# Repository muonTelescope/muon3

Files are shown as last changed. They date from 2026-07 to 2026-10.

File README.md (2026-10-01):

# Muon3: a networked cosmic-ray muon station

**In plain English:** muons from cosmic-ray showers pass through us all the time. A plastic scintillator tile gives off a
tiny flash when one crosses it. A silicon photomultiplier (SiPM) turns that flash into a current pulse, and a small board
counts pulses that arrive in several stacked tiles at once. Muon3 is the next-generation station for the Georgia State
University [gLOWCOST](https://cosmic.gsu.edu/) network: cheap, identical detectors in classrooms and labs that log how the
muon rate follows air pressure, temperature and space weather.

A station is **four decommissioned sPHENIX inner-HCal tiles** (Hamamatsu S12572-33-015P SiPMs), stacked 100 mm apart in a
printed ABS frame. Each tile carries one wavelength-shifting fiber in a closed loop, under a reflective coating and a
light-tight wrap. **One 337 × 40 mm, 4-layer, USB-powered board**, assembled by JLC on one side, stands behind the tiles with
its long axis along the stack: its four channel cells sit right behind the four SiPM boards, so the four micro-coax cables are
short (57 mm) and identical. The hub (USB-C, ESP32, bias supply, pressure/temperature) sits between tiles 1 and 2. A printed
three-segment case covers the board. There is no display: the station reports over USB and Wi-Fi.

| | |
|---|---|
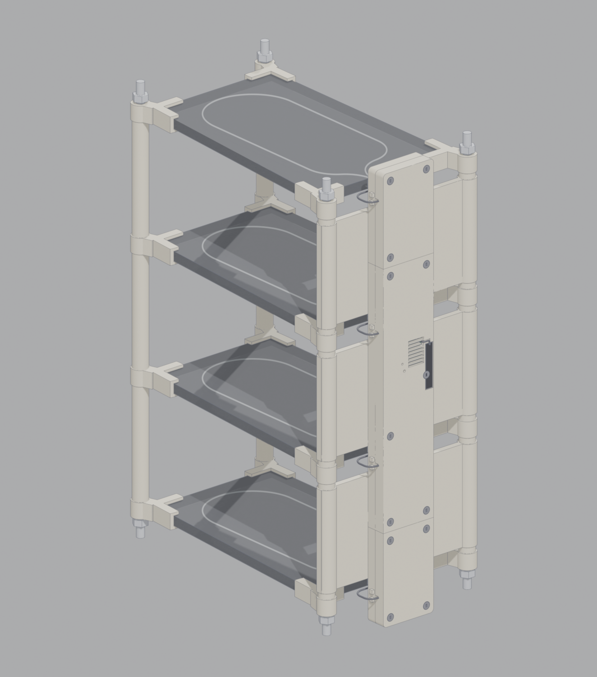
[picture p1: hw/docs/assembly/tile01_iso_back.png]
The station, from behind
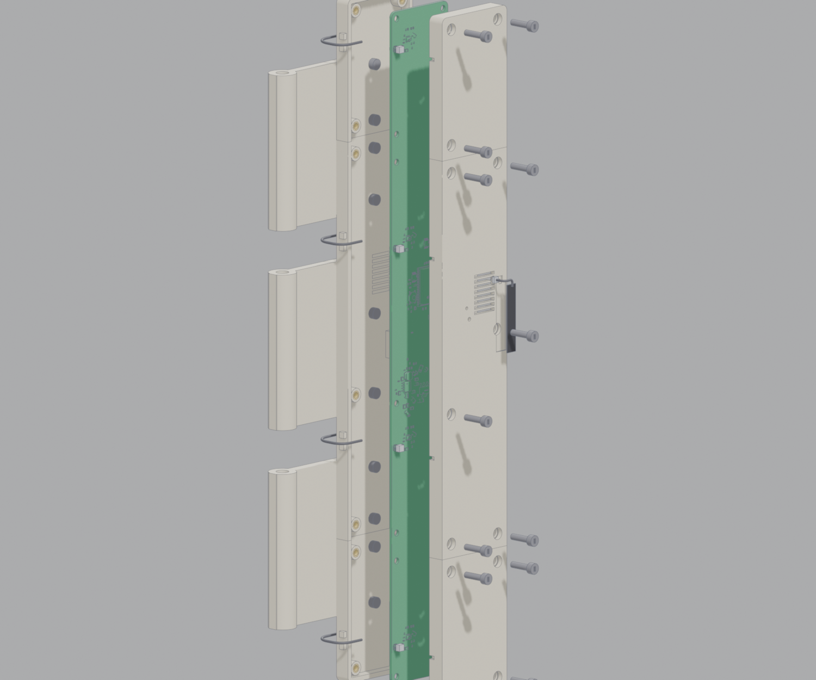
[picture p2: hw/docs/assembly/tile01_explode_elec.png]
Electronics, exploded
|  |  |

## Contents

0. [Quick start](#quick-start) · [How a muon becomes a count](#how-a-muon-becomes-a-count) · 1. [What you get](#1-what-you-get) · 2. [Bill of materials and cost](#2-bill-of-materials-and-cost) · 3. [Install it: step by step](#3-install-it-step-by-step)
· 4. [Test and calibrate](#4-test-and-calibrate) · 5. [The 12 tile shapes](#5-the-12-tile-shapes) · 6. [The electronics](#6-the-electronics)
· 7. [Simulated performance](#7-simulated-performance) · 8. [Regenerate the design files](#8-regenerate-the-design-files)
· 9. [Design notes, open questions, repository map](#9-design-notes-open-questions-repository-map)

---

## Quick start

```bash
git clone git@github.com:muonTelescope/muon3.git && cd muon3/hw
bun run parts && bun run build && bun run drc      # the board: Gerbers, BOM, CPL in hw/out/ (section 8 lists the tools to install first)
freecadcmd case/case.py                            # the three case segments
TILE=6 freecadcmd case/assembly.py                 # the frame, plate and tile stack for tile shape 6 (any of 1–12)
python tools/station_test.py board                 # factory test over USB, once a board is assembled
```

## How a muon becomes a count

1. **Light.** A cosmic-ray muon crossing a 7 mm polystyrene tile deposits about 1.5 MeV and makes some 13 000 scintillation photons
   (blue, 420 nm). About 2 500 of them are absorbed by the 1 mm wavelength-shifting fiber in the tile and re-emitted at 476 nm (green);
   light trapped in the fiber travels both ways round the closed loop to the SiPM. Of the order of 150 photons reach the SiPM and about
   35 are detected (PDE 25 %): the **photoelectrons (p.e.)**.
2. **Current.** The S12572 SiPM, biased at 53–83 V, turns each p.e. into a fast current pulse (gain about 2.3 × 10⁵). The bias comes from
   the MC34063 boost converter on the board and reaches the SiPM over the same micro-coax that carries the signal back.
3. **Voltage.** A transimpedance amplifier (OPA356, 33 kΩ) gives 5.8 mV per p.e., so a mean muon makes a 209 mV pulse about 370 ns long.
4. **Decision.** A comparator (LMV7219) fires when the pulse passes a threshold set by a DAC: 29 mV, 5 p.e., rejects dark counts (single
   p.e.) and keeps essentially every muon that crosses the tile.
5. **Count.** The ESP32-S3 time-stamps each edge (MCPWM capture, 12.5 ns) and counts singles (PCNT); coincidences of the four tiles are
   formed in firmware, together with pressure and temperature (BME280), and sent over Wi-Fi or USB. The muon rate follows air pressure,
   temperature and space weather: that is what the gLOWCOST network logs. `sim/python/coincidence_rates.py` computes the coincidence and
   accidental rates; `sim/python/sipm_to_tot.py` maps SiPM charge to time over threshold.

---

## 1. What you get

- **Identical channels.** Channel 0 is placed and routed once; cells 1–3 are exact copies at a 100 mm pitch (copper identical
  to 2 µm, checked on every build with `hw/tools/cell_identity.py`). The pitch is the tile pitch, so cell *k* is behind tile *k*.
- **The SiPM bias never leaves the case.** Each tile's micro-coax plugs into a U.FL jack inside the case.
- **External antenna.** An ESP32-S3-WROOM-1U-N16R8 sends its Wi-Fi/BLE through a U.FL pigtail to a flat antenna on the lid.
- **Fits every tile.** All 12 inner-HCal tile shapes, from the 121 mm wide, nearly rectangular tile 01 to the 403 mm
  parallelogram tile 12, get a frame and a fiber loop generated from their outline.
- **Self-testing.** The board tests itself over USB in 2 minutes (nothing plugged in), and calibrates each tile's gain from its
  own dark counts.

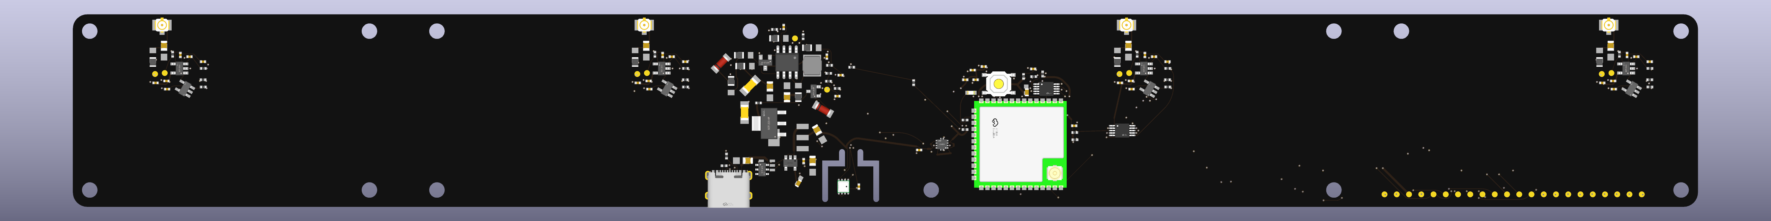
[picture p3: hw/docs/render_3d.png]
The board, 337 × 40 mm: four channel cells along the top edge, the hub with USB-C, BME280 island and ESP32 in the middle, the probe row at the right


```text
 tile ─ micro-coax ─► U.FL in the case (shell = bias via 47 kΩ) ─► OPA356 TIA (33 kΩ ‖ 2.7 pF) ─► LMV7219 ─► HIT_n ─► ESP32-S3
   ×4 (identical cells)           ▲                               ▲ VREF (DAC B·A)             ▲ VTH_n (DAC A)      PCNT + MCPWM
             MC34063 boost → 10 k / 1 µF RC ─ HV (53–83 V) ◄─ HV_TRIM (DAC B·B) ◄──────────────────────────── HV_EN
                         └──────────── HV_MON (÷ 27.7) ────────────────────────────────────────────────────► ADC
 INJ (GPIO) ─ 10 k/1.1 k ─ 1 pF into each input: 0.33 pC = 9 p.e. self-test
 BME280 (slotted thermal island, ≥ 20 mm from any input) · SC7A20H tilt · USB-C 5 V → AMS1117 3V3 + TLV75733 3V3A
```

---

## 2. Bill of materials and cost

### Board (JLC assembles it; 155 parts, 45 lines)

Upload `hw/out/muon3-gerbers.zip`, `hw/out/bom.csv` and `hw/out/cpl.csv` to JLCPCB: **4 layers, 1.6 mm, top-side assembly only**,
337 × 40 mm. Parts come from LCSC; the full list is [`hw/parts/INDEX.md`](hw/parts/INDEX.md).

| Line | Part | Per board | Share |
|---|---|---|---|
| BME280 (pressure, temperature) | C92489 | $4.46 | 27 % |
| ESP32-S3-WROOM-1U-N16R8 (Wi-Fi, BLE, U.FL antenna connector) | C3013946 | $4.10 | 24 % |
| MCP4728 DAC × 2 | C478093 | $3.06 | 18 % |
| OPA356 TIA × 4 | C183100 | $1.83 | 11 % |
| LMV7219 comparator × 4 | C20613263 | $0.99 | 6 % |
| U.FL jack × 4, SC7A20H, AMS1117, MC34063, TLV75733 | | $0.95 | 6 % |
| the other 34 lines, mostly 0402/0805 passives | | $1.19 | 7 % |

**Cost at 100 boards (importer: GSU): parts $16.58 + PCB $6.19 + JLC assembly $1.32 = $24.08 ex-works, $35.57 landed in the US**
($105.57 per board for the two Berlin prototypes). The PCB price is an estimate ($0.045 per cm² of 4-layer board, 135 cm² here): get a
quote. Cheaper variants (saves about $6.3 per board, landed $35.6 → $26.4): BME280 → SPA06-003 (same package, pressure + temperature,
$0.51), drop the second MCP4728 (fixed VREF divider, PWM HV trim), ESP32 N4 module, drop the tilt sensor, two extended parts →
basic parts. Not worth it: a 2-layer board (saves $1.50, loses the ground plane), dropping the analog LDO, cheaper op-amps.

### Mechanics and cables (you print and buy these)

| Part | Qty | How |
|---|---|---|
| Corner clip (ABS, 12.4 mm thick, 8.0 mm slot, M6 hole) | 16 | printed, flat |
| Spacer tube (Ø 12 / Ø 6.4) | 18 (6 × 87.6 mm, 12 × 4.8 mm) | printed; the long ones can be aluminium tube |
| Back plate bar (one piece for tiles 1–11; two halves + a splice plate for tile 12) | 3 | printed, lying on its back |
| Case base + lid, segments A (71 mm), B (200 mm), C (71 mm) | 3 + 3 | each flat |
| M6 threaded rod, about 345 mm | 4 | cut from 1 m stock |
| M6 nut + washer | 8 + 8 | |
| M3 × 5.7 heat-set insert | 13 (lid) + 10 (plate bars) (+ 12 for the tile-12 splices) | pressed in with a soldering iron |
| M3 × 12 socket-head screw (ISO 4762) | 13 | lid, through the board's edge holes |
| M3 × 6 socket-head screw (ISO 4762) | 10 (+ 12 for the tile-12 splices) | case floor to plate bars |
| U.FL to U.FL micro-coax, Ø 1.13 mm, 70 mm | 4 | tile SiPM board to station board; four equal lengths |
| 2.4 GHz FPC antenna, 35 × 7 mm, with U.FL pigtail | 1 | sticks in the lid recess |
| Tile wrap: 100 µm Al foil, 30 µm cling film, 100 µm black vinyl, epoxy (EPO-TEK 301 class) | 4 tiles | plus the tile's 50 µm painted reflector |
| 4 decommissioned sPHENIX inner-HCal tiles with their fibers, SiPMs and SiPM boards (from GSU) | 4 | of one shape |

Print in ABS at 0.2 mm layers, 4 perimeters, 30 % infill, 100 °C bed, enclosure closed. The longest parts are case segment B
(206 mm) and the plate bars (up to 212 mm): both fit a 220 mm bed.

---

## 3. Install it: step by step

All M3 joints are **socket-head screws into heat-set inserts** (no nuts, no glue). Press the inserts in first: hold each on its hole
with a soldering iron at 220–240 °C and push it flush. Everything below is generated for your tile shape (1–12): run the commands in
[section 8](#8-regenerate-the-design-files) with `TILE=<n>` to get the exact STL/STEP files.

### Step 0: order and print

1. Order the board (section 2). Order or print the parts (`hw/out/case/case_{base,lid}_{A,B,C}.stl`, and the clips, spacers and bars
   from `hw/out/assembly/tileNN/`).
2. Check the board when it arrives: `python hw/tools/station_test.py board` (section 4).

### Step 1: the tiles

The tile is a slab of extruded polystyrene with **one Kuraray Y11 fiber laid in a closed loop**: both ends leave the flat SiPM edge
side by side, each runs through an S-bend of 25 mm radius onto a leg, the two legs run down the tile and a semicircle closes the
loop near the far edge. Over the tile go the **50 µm painted reflector** and the **wrap: 100 µm aluminium foil, 30 µm cling film,
100 µm black vinyl**, each following the tile's outline and open only where the coupler sits (Aidala et al., IEEE TNS 65 (2018),
Table II and Fig. 6). Tiles 01, 06 and 12, bare, with the fiber in its groove and the coupler and SiPM board on the SiPM edge:

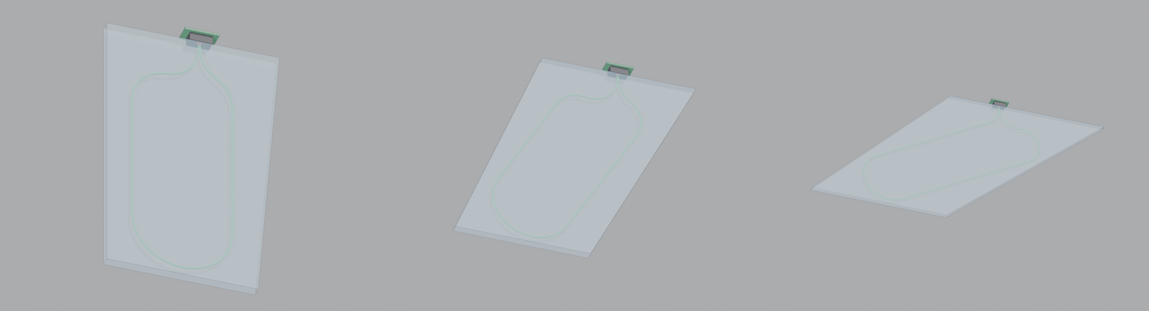
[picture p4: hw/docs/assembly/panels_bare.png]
Panels 01, 06 and 12


The same tile with its layers lifted off one by one (reflector, foil, cling film, vinyl):

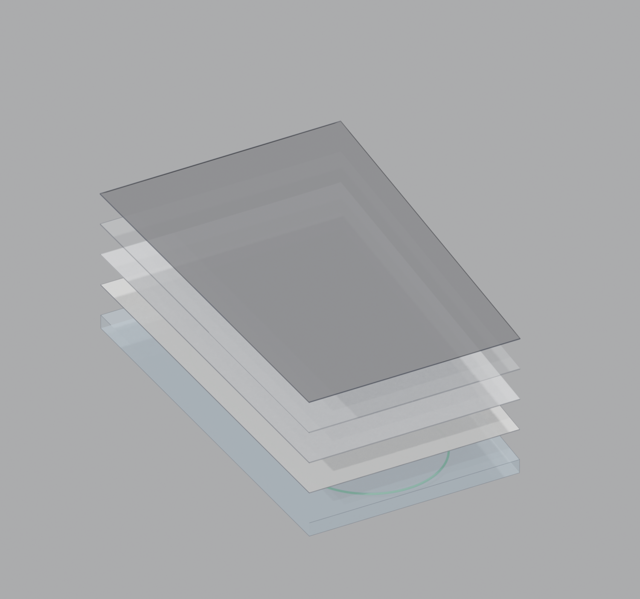
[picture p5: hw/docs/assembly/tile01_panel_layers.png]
Coating and wrap layers


1. Lay the fiber in its groove (epoxy) and cut and polish both ends flush with the SiPM edge.
2. Put on the reflector and the wrap (foil, cling film, vinyl), open at the coupler.
3. Glue the coupler block (16 × 6 × 8 mm, black ABS) on the SiPM edge over the two fiber ends, with the SiPM board and its U.FL
   jack behind it. Both ends, 1.2 mm apart, face the one 3 × 3 mm SiPM across a 0.75 mm air gap.

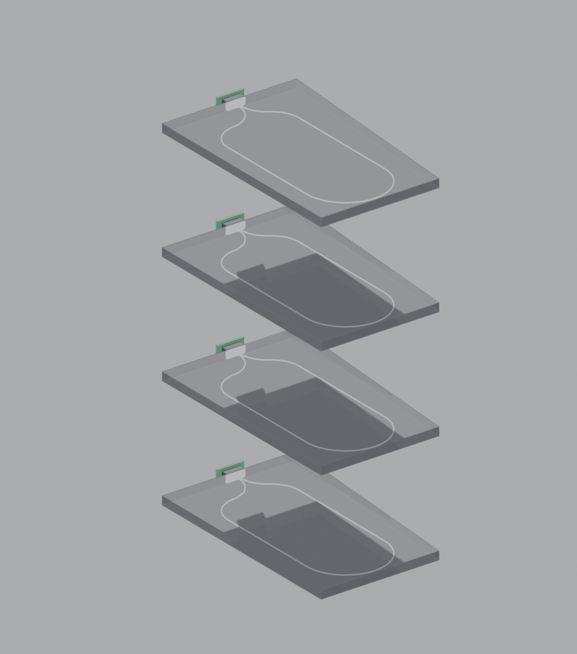
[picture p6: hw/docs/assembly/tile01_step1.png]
Step 1


### Step 2: the frame

Slide the four rods through the bottom clips, add the nuts, then build up: spacer, tile in its four corner clips, spacer, next tile.
The four clips of a tile clamp its corners in an 8.0 mm slot; the tile is never drilled. The rods sit 8.5 mm outside each corner, so
they never touch the scintillator.

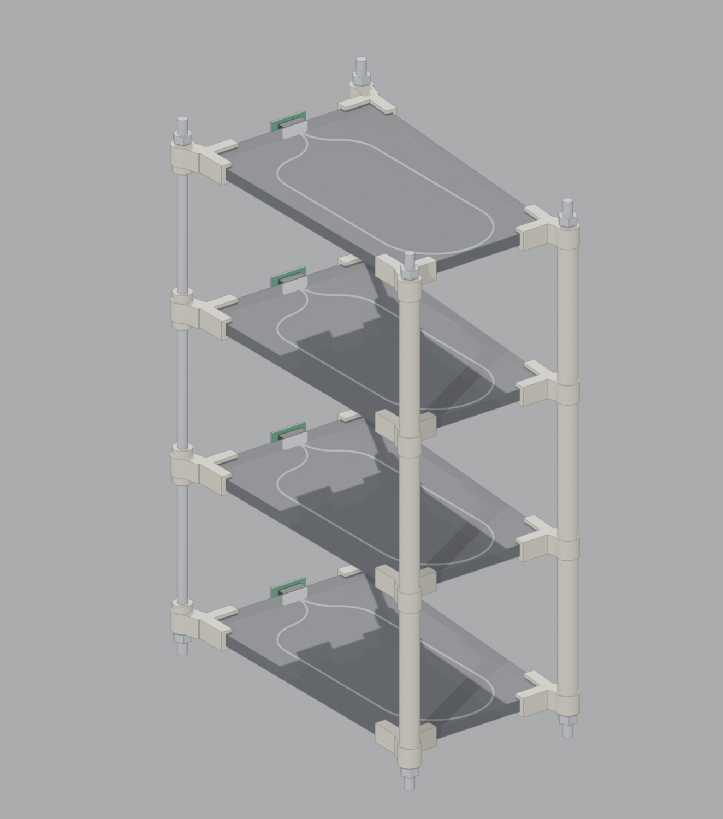
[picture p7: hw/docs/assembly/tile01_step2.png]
Step 2


### Step 3: the back plate

A bar replaces the back-rod spacer between tiles 0/1, 1/2 and 2/3. Each bar's two sleeves slide onto the back rods (bars are at
z = 50, 150 and 250 mm, clear of the SiPM boards at z = 0, 100, 200, 300, so the coax passes between them). For tile 12 each bar is
two halves joined by a splice plate on the front face (4 × M3 × 6).

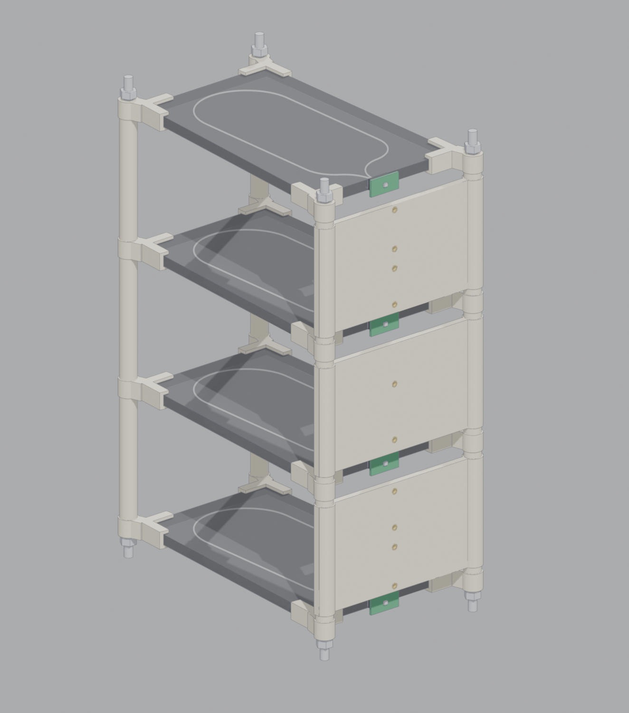
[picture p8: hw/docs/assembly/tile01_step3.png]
Step 3


### Step 4: the electronics

Press the inserts into the three case bases. Drop the board onto the bosses of the bases (the board's underside has no parts; the
heads of the floor screws sit in the 4.6 mm gap under it), close the three lids (13 × M3 × 12) and screw each segment's base to the
bars (10 × M3 × 6). The segments join at the bars (board x = 68.5 and 268.5 mm). The USB-C opening is on the far long wall, the
BME280 vent beside it.

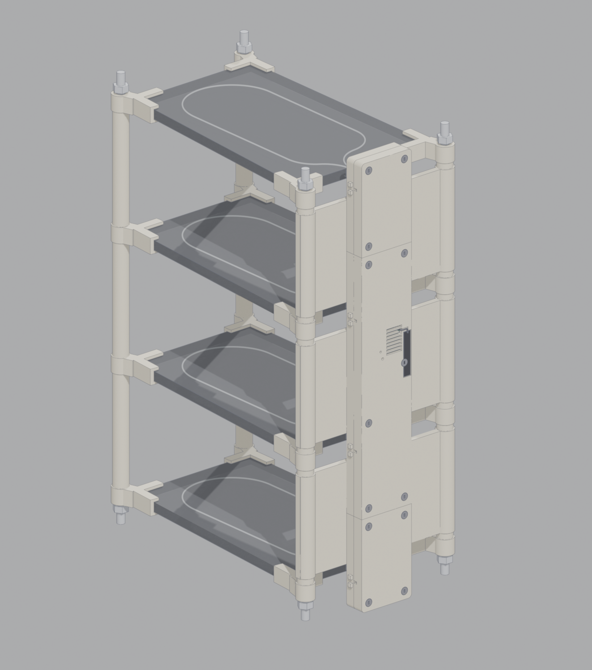
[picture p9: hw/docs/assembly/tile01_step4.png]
Step 4


### Step 5: cables and antenna

Plug a 70 mm micro-coax onto each tile's SiPM board, route it out to the case wall, and click its other plug onto the board's jack
through the notch in the lid skirt, then lay it in the zip-tie bridge on the wall. All four cables are identical. Stick the FPC antenna
in the lid recess and click its pigtail onto the ESP32 module's U.FL through the lid hole.

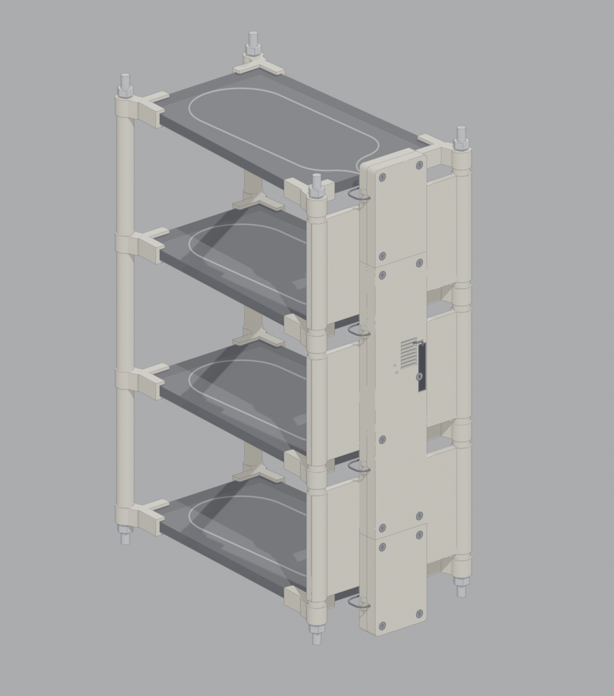
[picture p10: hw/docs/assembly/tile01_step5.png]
Step 5


### Sections (tile 01)

Through the SiPM edge (scintillator with its coating and wrap, fiber in its groove, coupler, SiPM, board, plug) and through the case
at the hub (lid, board on its 4.6 mm standoffs, base, plate bar):

| | |
|---|---|
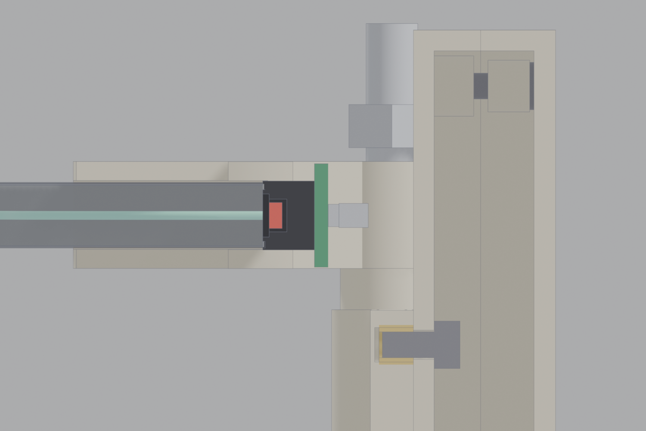
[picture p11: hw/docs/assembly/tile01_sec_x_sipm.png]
SiPM section
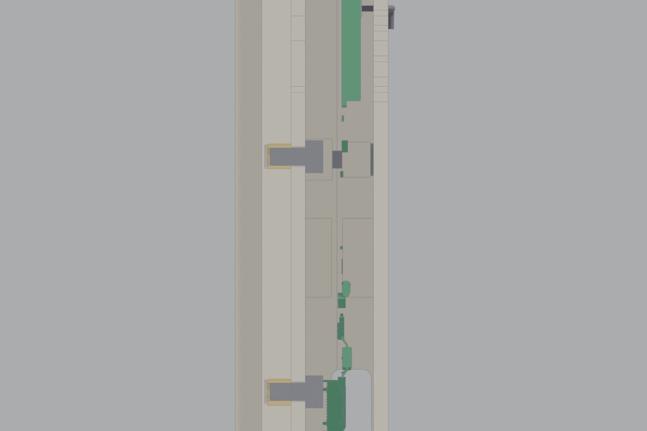
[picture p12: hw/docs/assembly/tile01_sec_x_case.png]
Case section
|  |  |

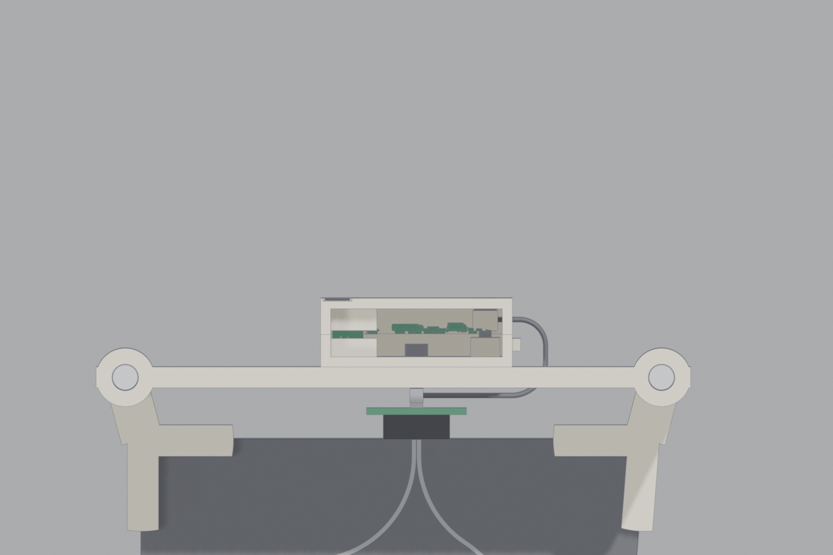
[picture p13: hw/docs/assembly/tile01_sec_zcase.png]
Case, plate bar and cable, cut at the hub


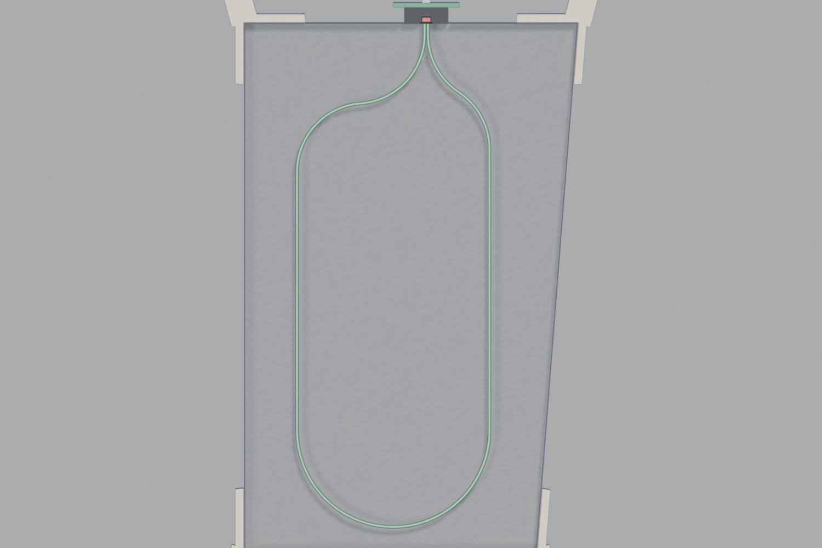
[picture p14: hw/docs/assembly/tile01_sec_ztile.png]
Fiber in the top tile, cut at its mid-plane


The widest shape (tile 12), from the back:

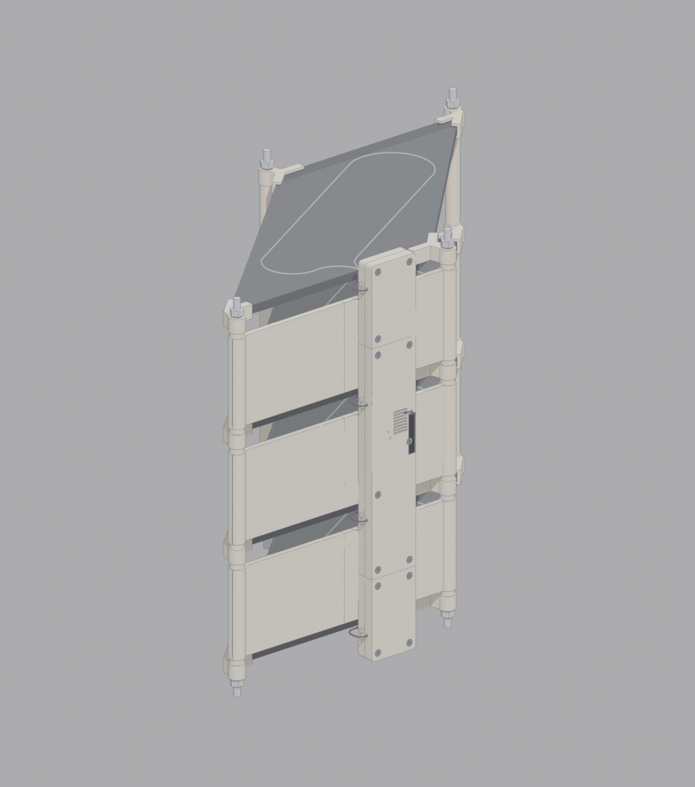
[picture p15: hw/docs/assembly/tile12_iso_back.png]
Tile 12 from the back


### Case and plate details

- **Three printed segments** (71, 200, 71 mm, each with a base and a lid, split at the board mid-plane) because the board is 337 mm long;
  the joints sit on the plate bars. The lid screws sit 7 mm either side of a joint so that no boss is cut.
- **Coax entry.** A 1.8 × 2.4 mm notch in the lid skirt above each U.FL takes the micro-coax; a small zip-tie bridge on the wall takes the
  strain off the plug. The bias on the U.FL shells stays inside the closed case.
- **BME280 chamber.** Ribs above and below the island (stopping 0.15 mm short of the board), vented to room air through eight 1.6 mm
  slots in the far wall. **Hot side:** eight 1.6 × 14 mm chimney slots in the floor and lid over the ESP32 and AMS1117.
- **External antenna.** A Ø 3.2 mm hole in the lid over the module's U.FL jack passes the pigtail to a 35 × 7 × 0.7 mm recess on the
  lid's outer face, along the far edge.
- **Mounting.** Ten Ø 3.4 mm holes in the base floors take M3 × 6 screws into the bars' inserts (two per segment per bar).

### Step 6: install

Put the stack where it will stay (tiles horizontal). Plug a USB-C power source into the hub's USB-C port (a bank that can deliver
the station's 40–120 mA continuously: many switch off below 50–100 mA). Give it Wi-Fi credentials over the USB serial port.
*(The firmware is not written yet: its USB line protocol is specified in `hw/tools/station_test.py`.)*

---

## 4. Test and calibrate

Every board is tested and calibrated by the ESP32 itself, driven from a laptop over USB:

```bash
python hw/tools/station_test.py board          # factory test: nothing plugged in, about 2 min
python hw/tools/station_test.py tile --ch 0    # per tile, at installation: about 10 min per channel
```

No scope or fixture is needed. The probe row (22 pads, 2.54 mm pitch, far long edge at the right-hand end of the board) and the
TIA/GND scope pair in each channel cell are for diagnosing a board that fails. The station has one status LED (next to the BOOT
button, through a light pipe in the lid): the firmware is specified to blink fast during the 10 s self-test, slowly while counting and
to stay on in a fault.

**How it works.** Each channel has a 1 pF injection capacitor driven from the INJ GPIO through a 10 k / 1.1 k divider: each edge puts
0.33 pC on the TIA input, which is 9 photoelectrons (p.e.). The firmware sweeps the threshold DAC and counts HIT pulses: the threshold
at which half the injected pulses still fire measures the whole chain at once. The bias checks itself through HV_MON (HV ÷ 27.7). The
tile calibrates its own gain: in the dark a SiPM fires single p.e., the count rate against threshold falls in a staircase, and the step
spacing is 1 p.e. (set the bias so it is 5.8 mV, then put the threshold at 5 p.e. = 29 mV). The same staircase, repeated every few
minutes, is the running gain servo.

### Factory test (`board`)

| Step | What the firmware does | Pass | Source |
|---|---|---|---|
| 1 | Scan both I2C buses | BME280 0x76, SC7A20H 0x19, MCP4728 0x60 on I2C0 and I2C1 | design |
| 2 | Read BME280 pressure | 850–1090 hPa | — |
| 3 | HV_EN low, read HV_MON | 2.5–5.5 V (USB 5 V minus the boost diode; not 0 V) | [SIM] ≈ 4 V |
| 4 | HV_EN high, TRIM = 0 / 1.0 / 2.048 V | 80–86.5 V / 65.5–71.5 V / 50–56 V | [SIM] 83.0 / 68.3 / 52.9 V |
| 5 | Store HV(TRIM) line; leave the bias at TRIM 2.048 V and HV_EN low | — | — |
| 6 | Per channel: VTH staircase with no injection | noise edge ≤ 8 mV below VREF | [SIM] < 3 mV |
| 7 | Per channel: VTH staircase with INJ pulses, 50 % point | 85–135 mV below VREF | [SIM] 109 mV |
| 8 | Join the test access point, read RSSI (the external antenna must be on the lid) | ≥ −65 dBm at 2 m | first prototype |

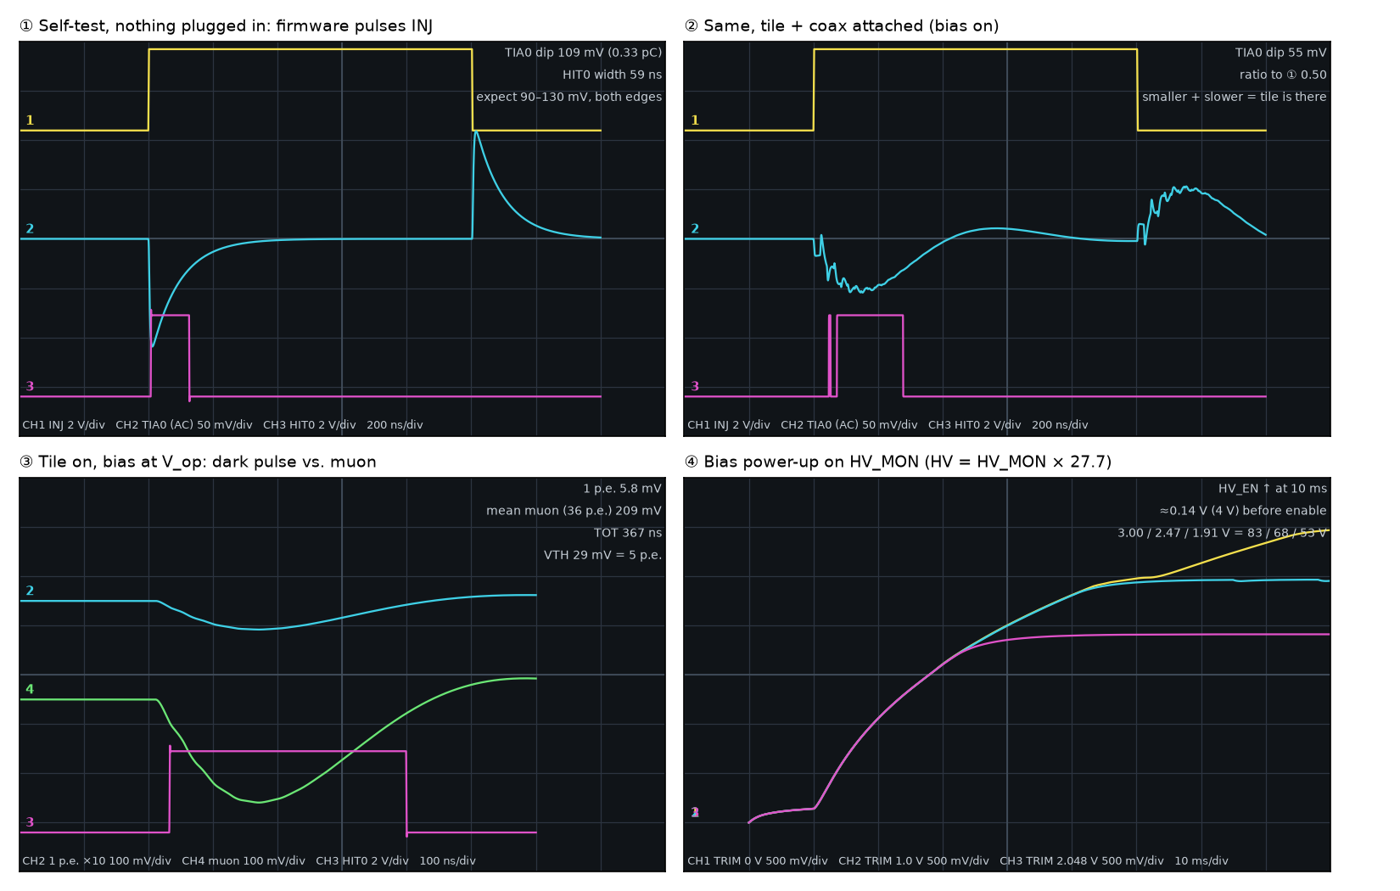
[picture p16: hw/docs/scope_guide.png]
Simulated scope screens


*Simulated scope screens (what you should see on the probe points): ① injection with nothing plugged in: a 109 mV dip follows each INJ
edge and HIT0 fires on the negative one. ② With a tile and coax attached the charge shares the SiPM's 320 pF and the dip halves (55 mV).
③ A single dark pulse (5.8 mV, shown ×10) and a mean muon (36 p.e., 209 mV, time over threshold ≈ 370 ns). ④ The bias power-up on
HV_MON: ≈ 4 V until HV_EN goes high at 10 ms, then 60–90 ms to settle.*

### Per-tile calibration (`tile`)

1. Attach the tile and close the light-tight wrap. Set the bias to the tile's operating voltage V_op (from the Hamamatsu/GSU sheet);
   the firmware closes the loop on HV_MON using the stored HV(TRIM) line.
2. **Staircase.** Sweep VTH 1–40 mV below VREF, 200 ms per step. The peaks in −d(log rate)/dVTH sit between p.e. steps; their
   spacing is the 1 p.e. amplitude.
3. If the step is not 5.8 mV, move V_op by ΔV = (5.8 / step − 1) · (V_op − V_bd) and repeat.
4. Threshold = 5 p.e.; store `pe_n`, `vth_n` and V_op in NVS.
5. With the tiles stacked, run the coincidence plateau: V_op ± 1 V in 0.25 V steps, 5 min each. The rate should be flat within its
   statistical error. Expect a few counts per minute for a 12 × 19 cm tile (cosmic muons: about 1 per cm² per minute × the geometric
   acceptance). Measure each tile's efficiency with the coincidence method (three tiles fire, does the fourth?).

### Diagnosing a failed board

| Probe (row, left → right) | Expect |
|---|---|
| GND · 5V · 3V3 · 3V3A | 0 · 4.8–5.2 · 3.25–3.35 · 3.25–3.35 V |
| VREF · VTH0–3 | as set (default 2.50 V; VTH = VREF − 29 mV) |
| HIT0–3 | 0 V idle, 3.3 V pulses |
| INJ | 0/3.3 V square during self-test |
| HV_EN · HV_TRIM · HV_MON | 0/3.3 V · 0–2.048 V · HV ÷ 27.7 |
| DAC_C · DAC_D | spare DAC outputs |
| SDA0 · SCL0 | I2C0, 3.3 V idle |

- Scope the TIA with a ground spring on the TIA/GND pair in each cell. **Never clip a scope ground to a U.FL shell: it carries the bias.**
  The four cells are identical, so a good channel next door is your reference.
- A TIA pinned at VREF with no injection dip: dead op-amp or open input. Pinned at a rail: shorted Cf/Rf or an input tied to the shell.
- HV stuck at ≈ 4 V with HV_EN high: the BSS123 gate (HV_GATE), the 150 µH inductor or the MC34063 current sense (2.2 Ω).
- No Wi-Fi with a good board: the antenna pigtail is not clicked onto the module's U.FL, or the FPC antenna is not on the lid.

---

## 5. The 12 tile shapes

The shapes differ a lot: tile 01 is almost a rectangle (121 × 191 mm); tile 12 is a 403 × 191 mm parallelogram leaning 45°. All are
drawn at the same scale (rods, corner clips, the fiber loop, the coupler on the SiPM edge at the top):

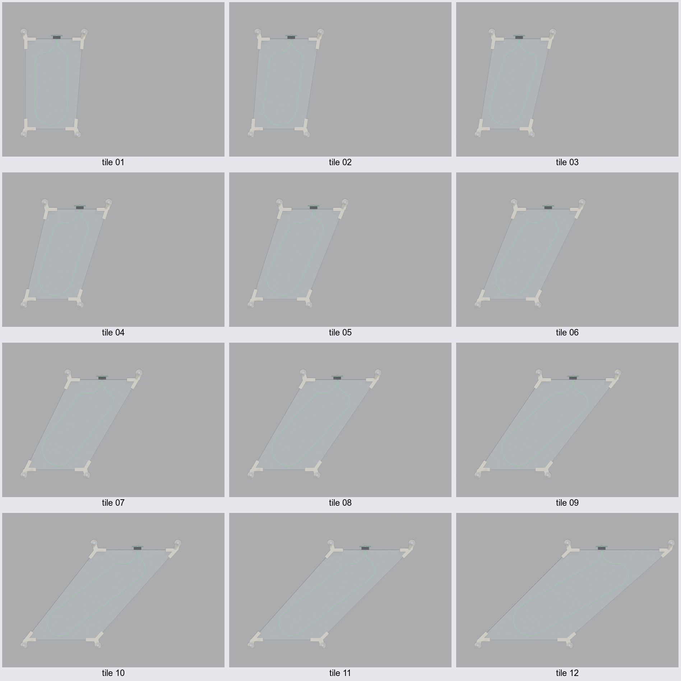
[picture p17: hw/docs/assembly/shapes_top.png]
All 12 tile shapes, same scale


<!-- SHAPES -->
| Tile | Bounding box (mm) | Left-edge slant | Stack footprint x × y × z (mm) | Fiber loop: lean, legs apart, length | Distance tile → fiber: mean / 95 % / max | Plate bars | Coax (mm) | ABS volume |
|---|---|---|---|---|---|---|---|---|
| 01 | 121 × 191 | 0° | 143 × 244 × 344 | 0.0°, 70 mm, 439 mm | 15 / 30 / 44 mm | 3 × 1 piece | 57 | 413 cm³ |
| 02 | 140 × 191 | 4° | 162 × 244 × 344 | 7.5°, 70 mm, 441 mm | 15 / 32 / 45 mm | 3 × 1 piece | 57 | 418 cm³ |
| 03 | 151 × 191 | 9° | 173 × 244 × 344 | 17.5°, 70 mm, 446 mm | 14 / 32 / 47 mm | 3 × 1 piece | 57 | 413 cm³ |
| 04 | 172 × 191 | 13° | 194 × 244 × 344 | 17.5°, 70 mm, 457 mm | 14 / 31 / 46 mm | 3 × 1 piece | 57 | 420 cm³ |
| 05 | 192 × 191 | 18° | 214 × 244 × 344 | 25.0°, 70 mm, 467 mm | 15 / 32 / 48 mm | 3 × 1 piece | 57 | 425 cm³ |
| 06 | 214 × 191 | 22° | 236 × 244 × 344 | 30.0°, 70 mm, 479 mm | 15 / 32 / 54 mm | 3 × 1 piece | 57 | 431 cm³ |
| 07 | 237 × 191 | 26° | 259 × 244 × 344 | 37.5°, 70 mm, 501 mm | 15 / 33 / 54 mm | 3 × 1 piece | 57 | 438 cm³ |
| 08 | 262 × 191 | 30° | 284 × 244 × 344 | 42.5°, 70 mm, 519 mm | 16 / 34 / 63 mm | 3 × 1 piece | 57 | 447 cm³ |
| 09 | 289 × 191 | 34° | 311 × 244 × 344 | 47.5°, 70 mm, 542 mm | 16 / 34 / 65 mm | 3 × 1 piece | 57 | 457 cm³ |
| 10 | 319 × 191 | 38° | 341 × 244 × 344 | 52.5°, 55 mm, 580 mm | 16 / 37 / 66 mm | 3 × 1 piece | 57 | 469 cm³ |
| 11 | 334 × 191 | 42° | 356 × 244 × 344 | 52.5°, 55 mm, 571 mm | 16 / 37 / 73 mm | 3 × 1 piece | 57 | 463 cm³ |
| 12 | 403 × 191 | 45° | 425 × 244 × 344 | 60.0°, 70 mm, 643 mm | 19 / 45 / 91 mm | 3 × 2 halves + splice | 57 | 535 cm³ |
<!-- /SHAPES -->

- **One fiber, one closed loop per tile.** The sPHENIX goal is a deposit within about 25 mm of a fiber. A single loop meets that only
  near its legs: the table gives the mean, 95 % and maximum distance from a point of the tile to the fiber (about 15 mm on average,
  30–45 mm at the 95 % mark, up to 90 mm in the corners of the long tile 12). `cad/sphenix_hcal/scripts/fiber_loop.py` chooses the lean,
  position and leg spacing (55–70 mm) that bring the fiber closest to each shape's area; the same loop feeds the Geant4 model and the CAD.
  The real tiles may use longer patterns on the wide shapes: **check against GSU's own drawings before cutting grooves.**
- **The coax is the same for all shapes** (the SiPM board is at the same x on every tile, the board's jacks at the same z as the SiPM boards).
- The source tile CAD (upstream sPHENIX GDML) has **no fiber, coupler, coating or wrap**; all four are added here from the published
  construction. It does have a 71 × 8.7 mm connector pocket in the SiPM edge, which the model fills (flat edge).

---

## 6. The electronics

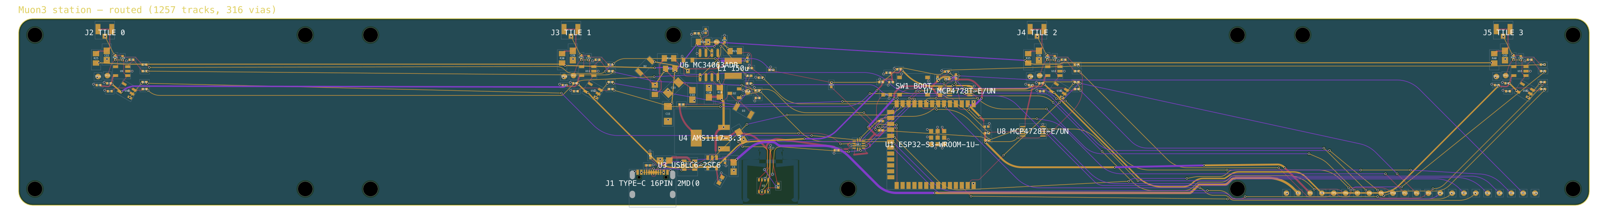
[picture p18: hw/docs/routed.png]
Routed copper


*The routed copper: tapered pad exits and parts at 15° steps where that shortens the nets.*

| | |
|---|---|
| Outline | 337 × 40 mm, 3 mm corner radius, 13 × M3 holes along the long edges (at both ends of each case segment and between) |
| Coordinates | Board x runs along the stack (x = tile z + 18.5 mm), board y across it; y = 0 is the edge the coax leaves by, y = 40 the USB-C / vent edge |
| Channel cells | 4 × (20 × 22 mm) along the coax edge, **100 mm pitch**. Each cell: a U.FL at x = 18.5 + 100k, y = 3, the 47 k / 100 nF bias feed, the TIA, the comparator and a TIA/GND scope pair. Placement, local copper, GND fan-out and silk are identical |
| Hub | x 130–207 mm, between cells 1 and 2: USB-C (x 136, far edge), bias and DAC feeds, charge injection, MC34063, AMS1117, the ESP32 (x 196, its U.FL faces +x), the BME280 island (x 156–167, far edge) |
| Stack-up | JLC 4-layer 1.6 mm: L1 signal + parts, **L2 solid GND**, L3 signal/power, L4 signal |
| Rules | 0.127/0.127 mm signal track/clearance; 0.5 mm for 5 V, 0.4 mm for 3V3, 0.3 mm for 3V3A and HV_SW; HV nets ≥ 0.26 mm to anything; 0.3/0.5 mm vias |
| BME280 island | 8.4 mm deep on the far long edge, ≥ 20 mm from any TIA input, cut free by two C-shaped slots; no plane and no plane vias on island and arm |
| Probe row | 22 pads at 2.54 mm at the right-hand end: GND 5V 3V3 3V3A VREF VTH0–3 HIT0–3 INJ HV_EN HV_TRIM HV_MON DAC_C DAC_D SDA0 SCL0 GND |
| Long nets | HV, 3V3A, VREF, INJ, VTH_n and HIT_n run 50–250 mm between the hub and the cells over the L2 ground plane; the TIA inputs stay inside their cells |

| Block | Parts | Notes |
|---|---|---|
| Input × 4 | Hirose U.FL-R-SMT-1(80) inside the case; shell = SiPM cathode = HVJ_n fed from HV via 47 kΩ with 100 nF to GND; centre = anode = SIG_n | The shell is the bias *and* the signal's AC shield. U.FL is rated 60 V AC rms / 200 V AC withstand; the bias tops out at 83 V DC |
| TIA × 4 | OPA356, Rf 33 k ‖ Cf 2.7 p, IN+ = VREF via 100 Ω / 100 nF | 5.8 mV per p.e.; 209 mV for the 36 p.e. mean muon |
| Discriminator × 4 | LMV7219, IN+ = VTH_n via 1 k / 100 nF, 33 Ω into the ESP32 | Threshold at 5 p.e. set by calibration |
| Self-test | INJ GPIO → 10 k / 1.1 k → 1 pF into every SIG_n | Each edge injects 0.33 pC = 9 p.e. |
| DACs | MCP4728 A (I2C0) = VTH0–3; MCP4728 B (I2C1) = VREF, HV_TRIM, DAC_C/D (spares) | Internal 2.048 V reference |
| Bias | MC34063 (2.2 Ω sense → 136 mA peak), BSS123, 150 µH, LL4148, 1 µF + 100 nF, 10 k / 1 µF RC post-filter; feedback 1.02 M / 20 k; TRIM → 1 k / 100 nF → 68 k into FB; HV_EN: a 2N7002 releases a clamp that otherwise holds FB high | **83.0 V at TRIM 0 V, 52.9 V at 2.048 V**; ≈ 4 V while HV_EN is low; HV_MON = HV ÷ 27.7 |
| MCU | ESP32-S3-WROOM-1U-N16R8: U.FL antenna connector, 16 MB flash, 8 MB octal PSRAM (IO35–37 reserved). USB on IO19/20 | PCNT singles, MCPWM capture (time stamp + time over threshold), coincidences in firmware |
| Power | USB-C 5 V (5.1 k Rd), USBLC6 ESD → AMS1117-3.3 (digital) + TLV75733 (analog) | No battery |
| Sensors | BME280 (0x76) on the island; SC7A20H tilt (0x19) | |

---

## 7. Simulated performance

All numbers come from simulations (`hw/sim/`, `sim/geant4/`); nothing has been measured on hardware yet.

| | Value | From |
|---|---|---|
| **Light: photoelectrons per muon that crosses a tile**, tile 01 | **36.6** (σ 13, min 15); every one of 272 crossing muons passes a 5 p.e. threshold. Tiles 03 / 06 / 09 / 12: 38.7 / 38.9 / 34.3 / 35.8 | Geant4, 150–300 muons per shape |
| Pulses: 1 p.e. / mean muon | **5.8 mV / 209 mV**, time over threshold ≈ 370 ns; threshold 5 p.e. = 29 mV | ngspice |
| Bias range | **52.9–83.0 V**; ≈ 4 V while HV_EN is low; settles in 60–90 ms | ngspice |
| Switching ripple at the TIA output | **0.04 mV pk-pk (0.007 p.e.)** (capacitor ESL, resistor shunt C, 1.5 nH shared ground) | ngspice, 5 ns steps |
| Injection self-test | 109 mV with no tile, 55 mV with a tile | ngspice |
| BME280 above room air | **+4.8 K** (low-power firmware), +8.8 K (Wi-Fi always on); mid-board would read +9.7 K | 2D thermal model |
| Wi-Fi at the TIA inputs (+20 dBm accepted, external antenna, cables included) | **0.9 / 1.6 / 9.3 / 1.1 mV peak** (cell 2 is 15 mm from the antenna feed), rectifying to ≪ 0.01 p.e. | openEMS |
| Cost at 100 boards | **$24.08 ex-works, $35.57 landed** ($16.58 parts, $6.19 PCB) | `bun run cost` |

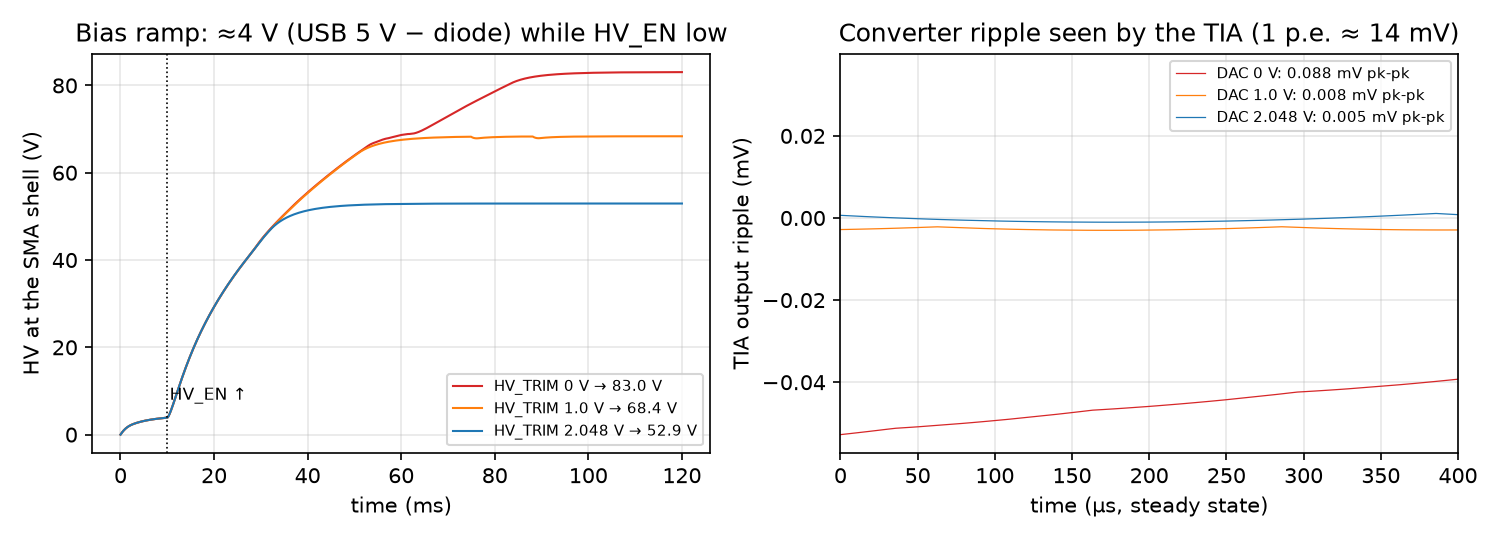
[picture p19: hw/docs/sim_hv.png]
Bias supply


### Light yield (Geant4)

The tile is modelled with one closed fiber loop, the 50 µm reflector (border surface, R = 0.95, Lambertian), the three wrap layers
(absorbing skin), the coupler and a Hamamatsu S12572-33-015P (flat PDE 0.25) across a 0.75 mm air gap. Material data: extruded
polystyrene + 1.5 % PTP + 0.01 % POPOP (n = 1.59, attenuation 2.2 m, 8000 photons/MeV, an estimate); Kuraray Y11(200) single-clad 1 mm
(PS core n = 1.59, PMMA cladding n = 1.49, EPO-TEK 301 groove n = 1.52, absorption 430 nm, emission 476 nm, attenuation 3.5 m).

| Tile | Generated / crossing | Fiber loop (length, mean distance tile → fiber) | p.e. per crossing muon: mean (σ), min | ≥ 5 p.e. |
|---|---|---|---|---|
| 01 | 300 / 272 | 439 mm, 14.5 mm | **36.6** (13.3), 15 | 100 % |
| 03 | 150 / 125 | 446 mm, 14.4 mm | **38.7** (14.9), 19 | 100 % |
| 06 | 150 / 107 | 479 mm, 14.9 mm | **38.9** (17.2), 15 | 100 % |
| 09 | 150 / 95 | 542 mm, 16.1 mm | **34.3** (10.8), 15 | 100 % |
| 12 | 150 / 97 | 643 mm, 18.8 mm | **35.8** (17.7), 6 | 100 % |

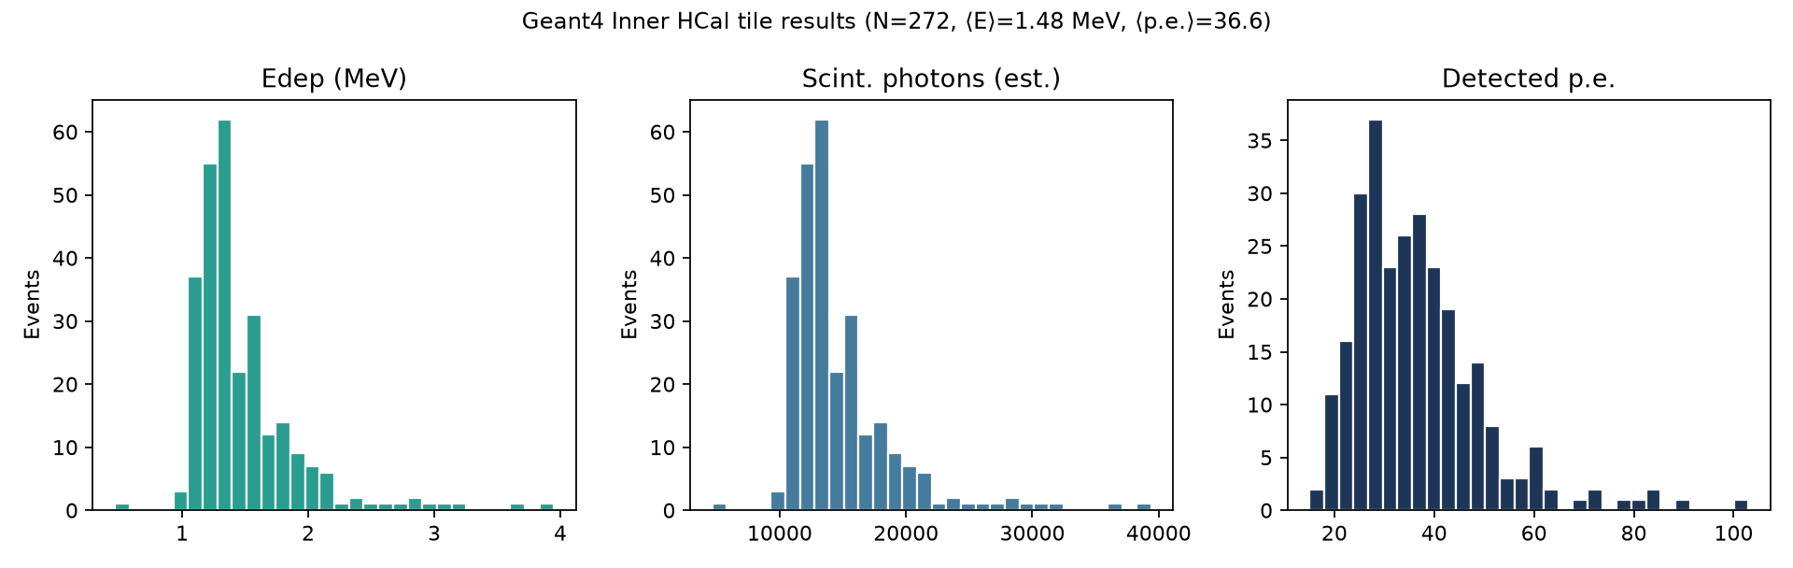
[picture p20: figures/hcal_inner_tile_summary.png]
Geant4 results


- The closed loop lets light that travels the far way round reach the SiPM: 36.6 p.e. against 21.5 for the earlier open loop (1.7 ×).
- "Crossing" means the muon deposited > 0.3 MeV; the gun is 50 mm above the tile and up to 50° off the vertical, so about 9 % of
  the muons miss the tile (more on the slanted shapes). That is a geometric acceptance loss, not a light-yield one.
- Per generated muon on tile 01: 13 100 scintillation photons → 2 540 absorbed by the fiber → 2 320 re-emitted → 156 reach the SiPM →
  33 detected.
- A first version of the loop (small, same size on every shape) gave only 24.7 p.e. on the 403 mm tile 12; the loop generator now fits
  the loop to the shape.
- **Not modelled:** the tile-to-tile variation of the groove, the polishing of the fiber ends, wrinkles of the wrap, SiPM cross-talk,
  after-pulsing and saturation (40 000 pixels, small at 36 p.e.). The yield depends on the fiber attenuation and on the light entering
  the fiber (the "WLS efficiency", 0.90): treat 36 p.e. as a simulation, not a prediction.
- Two earlier statements are withdrawn: "58 p.e. per muon" never came from the optical transport (an event-action fallback
  substituted a formula when no photon arrived; it is opt-in now, `HCAL_EFFECTIVE_YIELD=1`), and "90 % efficiency at 5 p.e." was the
  share of generated muons that hit the tile.

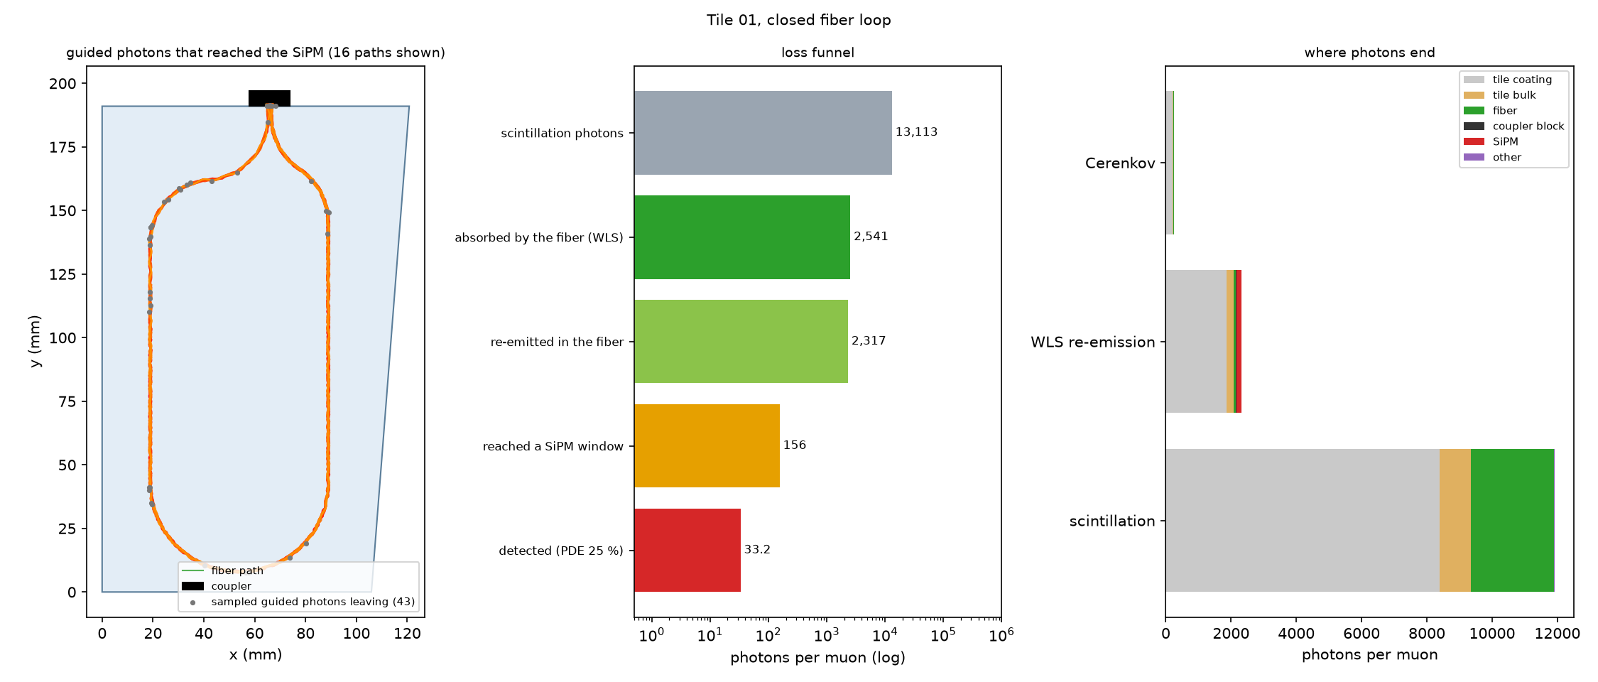
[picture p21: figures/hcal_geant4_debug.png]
Geant4 debugging: guided photons that reach the SiPM (left), the loss funnel (middle), where every photon ends (right)


How the transport was debugged (with the model as first written, 0.0–0.1 p.e. per muon; `HCAL_DEBUG=1` logs where every photon ends):
mirrored fiber pieces (`G4PVPlacement` takes the inverse rotation); Y11 absorption and emission overlapping on a coarse spectrum grid;
no refractive index on the SiPM (Geant4 kills the photon at the boundary); the reflector also sitting between tile and fiber; sharp
fiber corners and 3 mm chords (now 1° mitre-cut `G4CutTubs` chords: `G4Torus` joints made photons hop); the connector pocket (filled);
an impossible coupler (fiber ends 43 mm apart, from my old heuristic); and coating and wrap built as boxes round the bounding box (now
shells that follow the outline).

### Electronics

**Thermal.** The BME280 hangs on a slotted island on the far edge (no plane copper, four necked traces) in its own vented chamber and
reads +4.8 K above room air with low-power firmware (+8.8 K with Wi-Fi on). In the long layout the island is only 20 mm from the ESP32,
so it helps less than before. The design treats it as case temperature and takes SiPM gain from the dark-count staircase; for true tile
temperature, add a BME280 or TMP117 on a cable taped to the tiles.

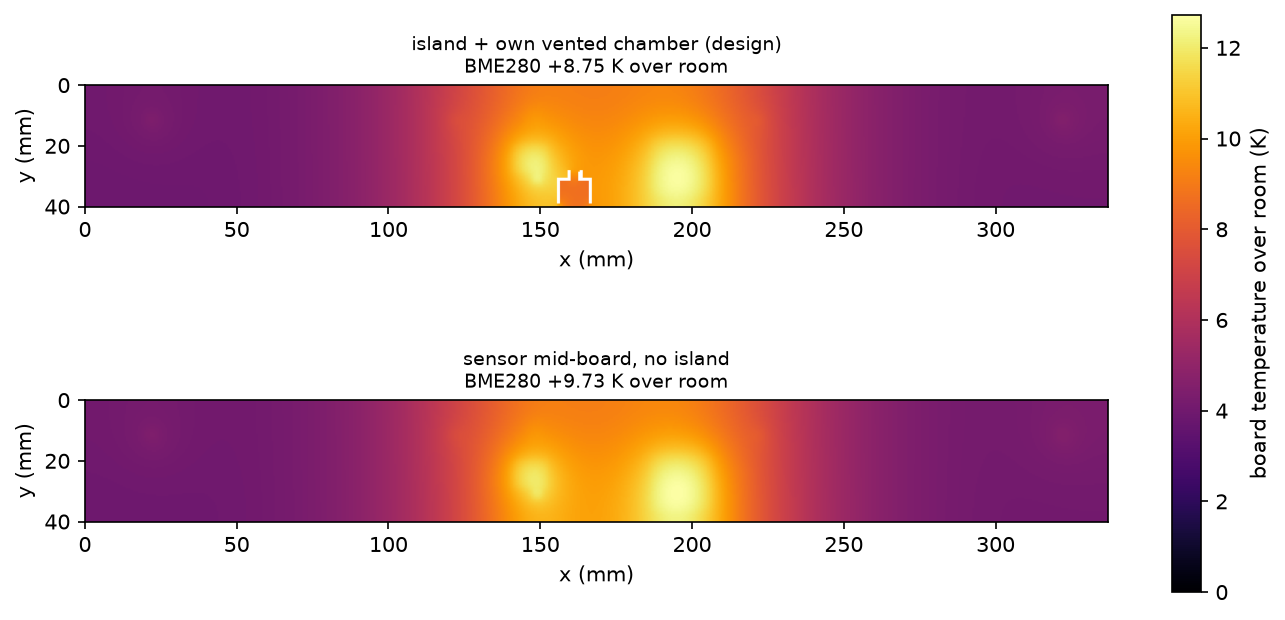
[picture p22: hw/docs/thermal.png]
Thermal model


**EMI.** The openEMS model (2.7 M cells) has the board, the case, the ESP32 can, the external inverted-L antenna on the lid, each
tile's coax shield leaving through the case wall, and the four input paths. With +20 dBm accepted the four TIA inputs pick up 0.9, 1.6,
9.3 and 1.1 mV peak at 2.44 GHz; a few mV at a CMOS op-amp input rectifies to microvolts. (In the earlier study metal cans or an ABS
cavity over the amplifiers did not help; not re-run for this layout.)

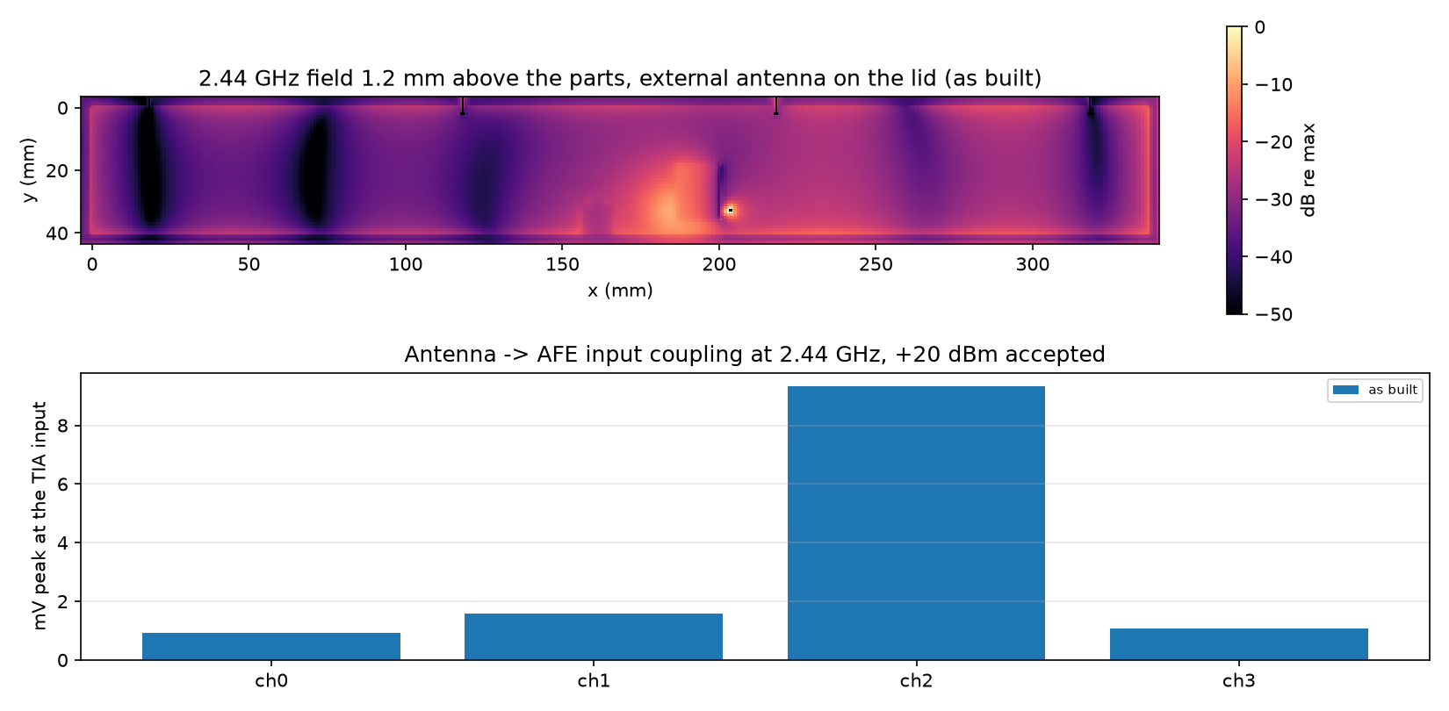
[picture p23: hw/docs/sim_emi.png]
EMI


---

## 8. Regenerate the design files

### Software you need

| Tool | Used for | Install (macOS) |
|---|---|---|
| [Bun](https://bun.sh) | board-as-code (TypeScript → Gerbers) | `brew install oven-sh/bun/bun` |
| KiCad 10 (`kicad-cli`, tested with 10.0.6) | DRC oracle, PCB STEP and 3D render | `brew install --cask kicad` |
| FreeCAD 1.x (`freecadcmd`) | case, frame and assembly | `brew install --cask freecad` |
| Blender 4.x | assembly renders | `brew install --cask blender` |
| Python 3 with numpy, matplotlib | fiber-loop generator, plots | `pip install numpy matplotlib` |
| ImageMagick (`magick`) | montages | `brew install imagemagick` |
| ngspice | bias, front end, scope screens | `brew install ngspice` |
| openEMS + Python bindings (optional) | EMI study | build from source against Homebrew (VTK 9.7); see the `CSXCAD_INSTALL_PATH=/opt/homebrew pip install --no-build-isolation CSXCAD/python openEMS/python` recipe |
| Geant4 11.4 (optional) | light yield | `micromamba create -p g4 -c conda-forge geant4 cmake make cxx-compiler` (about 3.5 GB) |

Heavy jobs (board build, FreeCAD, ngspice, openEMS, Geant4, Blender) go through `tools/memguard.sh -l <MB> -- cmd`, one at a time: the
8 GB development Mac crashed apps when they ran in parallel.

### Board

```bash
cd hw
bun run parts          # fetch footprints, pins, datasheets, STEP/OBJ for every LCSC part (once)
bun run build          # netlist → place → route → smooth → planes → silk → Gerbers/drill/BOM/CPL (~25 s) → hw/out/
bun run drc            # kicad-cli DRC: expect 0 errors (the "footprint library" warnings are harmless), 0 unconnected
python tools/cell_identity.py     # the four channel cells' copper must be identical
bun run cost           # BOM + JLC fees + freight/duty (Berlin prototypes, GSU/US batch)
```

### Case, frame and renders

```bash
cd hw
kicad-cli pcb export step --subst-models --no-dnp --force -o out/assembly/pcb.step out/kicad/muon3.kicad_pcb
freecadcmd case/case.py                              # the three case segments → out/case/
TILE=6 freecadcmd case/assembly.py                   # one shape (1–12) → out/assembly/tile06/ (SECTIONS=1 cuts section solids; TILE_STEP=1 writes cad/sphenix_hcal/step/*.step; STEP=1 the whole station)
sh case/build_assemblies.sh                          # all 12 shapes + Blender renders
python case/assembly_doc.py                          # copy renders to hw/docs/assembly/ and refill the table in this README
```

`out/assembly/tileNN/station.FCStd` is the hierarchical FreeCAD document:

```text
Station
├── Tiles ─ Tile_0 … Tile_3        (placed at z = 0, 100, 200, 300 mm)
│            └── Body (grooved PS) · Fiber (Y11, 1 mm, one closed loop) · Coating · WrapAl · WrapCling · WrapVinyl
│                · Coupler · SiPM · SiPM_PCB · UFL
├── Frame ─ Clip_k_FL/FR/BR/BL     (4 corner clips per tile)    Rod_×4 + Nut_×8    Spacer_×18
│            └── PlateBar_0/1/2 (one per gap: z = 50, 150, 250)  + inserts (+ splice plates for the widest shape)
├── Electronics ─ Case_Base_A/B/C · Case_Lid_A/B/C · PCB · LidScrew_×13 · LidInsert_×13 · MountScrew_×10
│                 · BoardPlug_×4 · Antenna_FPC · Antenna_Pigtail · Antenna_Plug
└── Cables ─ Cable_0 … Cable_3 (+ U.FL plugs)
```

### Tile data and fiber loops

```bash
python3 cad/sphenix_hcal/scripts/parse_inner_tile.py     # outlines, pocket, SiPM position, fiber loops → cad/sphenix_hcal/tile_params.json (about 25 s per tile)
python3 cad/sphenix_hcal/scripts/export_mesh_json.py     # → sim/geant4/gdml/mesh/*_mesh.json (read by Geant4)
```

### Simulations

```bash
cd hw && mkdir -p OUT/scope
sh sim/run_hv2.sh $PWD/OUT                     # bias supply at three DAC settings (ngspice)
(cd OUT/scope && ngspice -b ../../sim/scope_guide.cir)   # one channel: injection, 1 p.e., mean muon
python sim/plot_scope.py OUT                   # → docs/scope_guide.png
python sim/thermal.py                          # board + case-air thermal model → docs/thermal.png
python sim/emi_openems.py none OUT && python sim/plot_emi.py OUT    # 2.44 GHz coupling (openEMS)
```

```bash
cd sim/geant4 && mkdir build && cd build
cmake .. -DCMAKE_PREFIX_PATH=$CONDA_PREFIX && make -j2 hcal_tile      # in the conda env, -DEXPAT_LIBRARY/-DZLIB_LIBRARY (and *_INCLUDE_DIR) may be needed
G4BUILD=$PWD sh ../scripts/run_tile.sh 12 200 run12                   # tile 12, 200 muons → run12/muon_panel_hits.csv
HCAL_DEBUG=1 HCAL_DEBUG_EVENTS=20 ./hcal_tile run.mac                 # + photon_fate.csv, photon_tracks.csv (run.mac: /run/initialize, /run/beamOn N; ../macros/hcal_tile_run.mac and hcal_tile_vis.mac are ready-made)
python3 ../scripts/plot_hcal_tile_results.py --csv muon_panel_hits.csv
python3 ../scripts/debug_photons.py . ../gdml/mesh/InnerHCalTile01_EJ200_mesh.json debug.png
```

`HCAL_POCKET=1` keeps the connector pocket in the tile solid; `HCAL_EFFECTIVE_YIELD=1` restores the old formula fallback (not a transport result).

---

## Wright-style detector layouts (3 matched panels, printed + M3 only)

Five architectural layouts for one detector of **three identical tiles** stacked 100 mm apart and exactly registered, so triple-coincidence overlap is 100 % for a vertical track. Panel holders now carry LED strips (5 mm edge-lit strip inside the wall plus a visible light band on the outer wall). Everything except tiles, PCBs, SiPM, LEDs, fiber and wires is 3D-printed; every joint is an M3 cap screw with a captive hex nut. Models are built in ClassCAD (`tools/classcad/wright/`), rendered with `hw/case/wright/render.py`.

| Fallingwater (tile 7) | Guggenheim (tile 10) |
|---|---|
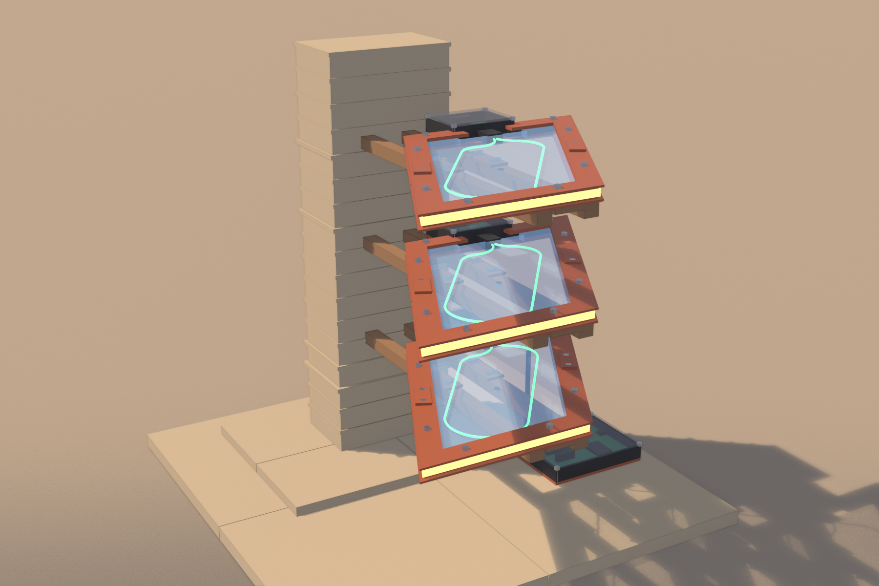
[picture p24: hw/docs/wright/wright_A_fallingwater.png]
Fallingwater
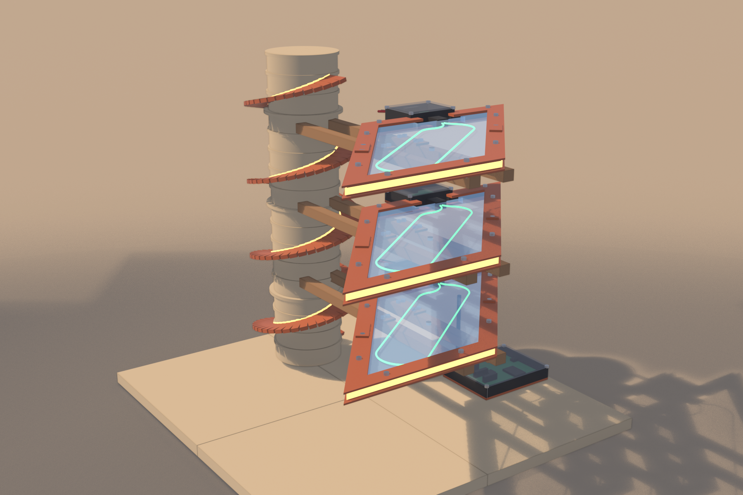
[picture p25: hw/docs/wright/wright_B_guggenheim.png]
Guggenheim
|  |  |
| **Robie (tile 9)** | **Hanna (tile 4)** |
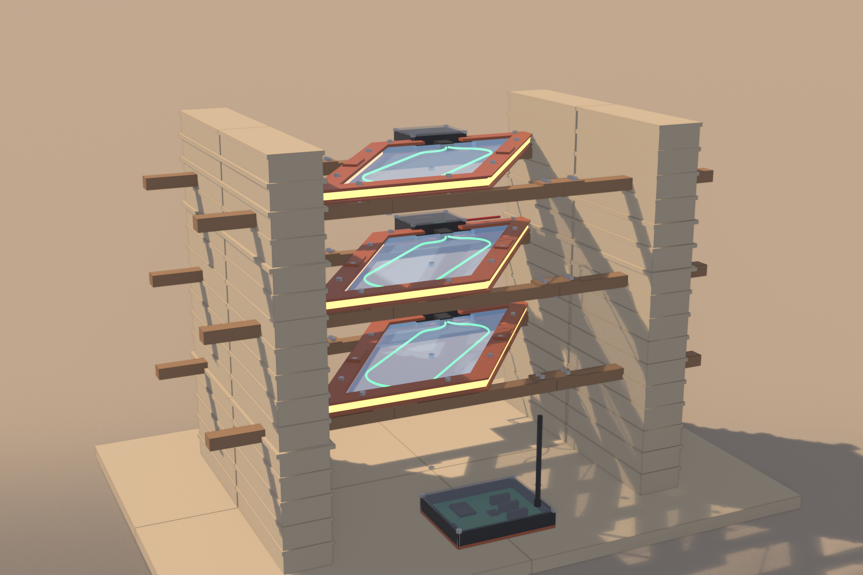
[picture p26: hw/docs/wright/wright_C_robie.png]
Robie
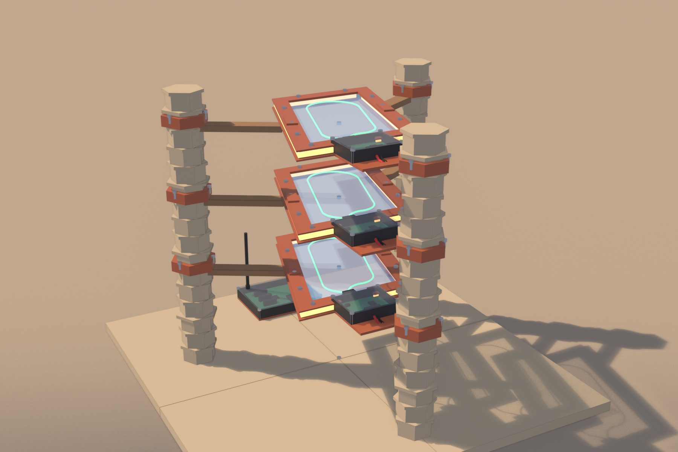
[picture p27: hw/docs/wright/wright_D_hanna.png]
Hanna
|  |  |

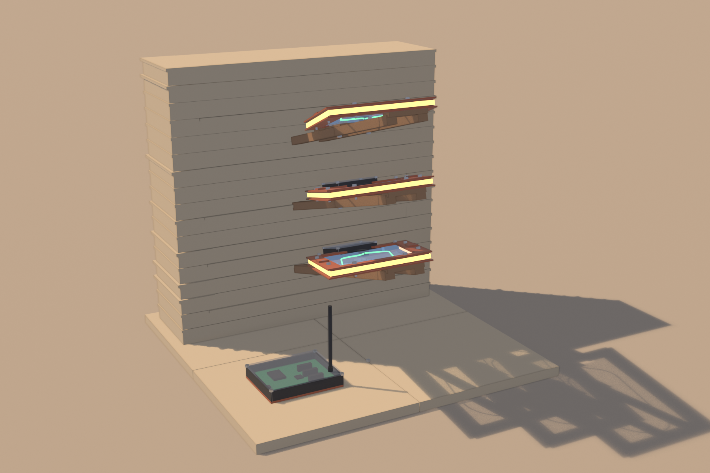
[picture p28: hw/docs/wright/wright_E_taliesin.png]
Taliesin (tile 5)


Regenerate: `python3 hw/case/wright/tile_data.py 7 10 9 4 5 && node tools/classcad/wright/build.mjs && blender -b --factory-startup --python hw/case/wright/render.py -- A hw/docs/wright`. Outputs (STEP/STL per material group, manifest) go to `hw/out/wright/<layout>/`. Geometry is generated, not print-tested; tile wrap, fiber and wire thickness are shown schematically, and tiles 11–12 are too wide for a 230 mm bed without a second holder split.

## 9. Design notes, open questions, repository map

### Design notes

- **The board follows the stack.** Channel cell *k* is at tile *k*'s height, so the coax is 57 mm and identical for all channels and all 12
  shapes. The price is copper area: 135 cm² instead of 61 cm² for the earlier 96 × 64 mm board.
- **Clips, not a tray.** Four small corner clips replace a tile-sized tray, so one design handles a 121 mm and a 403 mm tile.
- **Bias.** The earlier PWM trim spanned only 26–70 V; MCP4728 → 1 k / 100 nF → 68 k into FB gives 52.9–83.0 V, with a 2N7002 holding the
  boost off until HV_EN. The LC filter that rang at 2 V is an RC. 1 p.e. is 5.8 mV.
- **U.FL jacks inside the case** replaced edge SMAs whose shells carried the bias. The external antenna removes the PCB-antenna keep-out.
- **Footprints at any angle, tapered traces.** Small parts (up to six pads) may sit at any multiple of 15° when that shortens their nets by
  10 %; every track leaving a pad starts as wide as the pad's narrow side (up to 0.45 mm) and tapers to the net width in six steps.
- **Pipeline** (`hw/src/`): parts (LCSC/EasyEDA API) → circuit by pin name → placement (force + legalisation, identical channel cells) →
  0.1 mm grid A* router (3 layers, soft rip-up) → taut copper with arc fillets and pad tapers → L2 ground plane → silk → Gerber X2 with
  native arcs, Excellon with slots, BOM/CPL → KiCad export for DRC and 3D.

### Open questions and risks

- **The real fiber pattern and coupler.** The loop follows the published design; GSU's drawings of the inner-HCal tiles decide the actual
  grooves. On the widest shapes a single loop leaves corners up to 90 mm from the fiber; longer real patterns would raise the yield.
- **The U.FL voltage margin** (83 V DC against a 60 V AC rms rating, 200 V AC withstand) needs formal sign-off, although the bias no
  longer reaches an outside surface.
- **The long board.** Its price is an estimate, its long nets (HV, VREF, INJ, thresholds and hits, 50–250 mm) are unmeasured, and the
  three-segment case has not been printed and fitted.
- **Wi-Fi range** with the external antenna and the brass inserts is unmeasured (the test has an RSSI step: ≥ −65 dBm at 2 m). **USB
  power banks** often switch off below 50–100 mA; the station draws 40–120 mA.
- **The MC34063 reference is ±2 %**, about ±2 V on HV until the factory test stores each board's HV(TRIM) line.
- **Via-in-pad:** the GND fan-out drops vias inside large pads; order filled and capped vias or check JLC's terms.
- **Not done:** firmware (ESP-IDF; the USB protocol is specified in `hw/tools/station_test.py`); a real JLC quote; the EMI variants with
  cans or an ABS cavity for this layout; Geant4 for shapes 02, 04, 05, 07, 08, 10, 11.

### Repository map

| Path | What |
|---|---|
| `hw/src/` | Board as code: `design.ts` (netlist), `floorplan.ts` + `place.ts` (placement, identical cells), `router.ts` + `autoroute.ts` (routing), `copper.ts` (smoothing, tapers), `planes.ts`, `silk.ts` + `labels.ts`, `gerber.ts`, `jlc.ts`, `kicad.ts`, `drc.ts`, `build.ts` (the driver) |
| `hw/tools/` | `fetch_parts.ts` (LCSC/EasyEDA parts), `cost.ts` and `bom_cost.ts` (BOM and landed cost), `station_test.py` (factory test and the firmware's USB protocol), `cell_identity.py` (copper check) |
| `hw/case/` | `case.py` (three case segments), `assembly.py` (FreeCAD tile stack, frame, plate, cables), `render_assembly.py` (Blender), `assembly_doc.py` (copies renders, refills the shape table here), `build_assemblies.sh` |
| `hw/sim/` | ngspice (bias, front end, ripple, scope screens), `thermal.py`, `emi_openems.py` and their plot scripts |
| `hw/docs/` | The figures used in this README: board renders, simulation plots, `assembly/` renders |
| `hw/parts/` | The parts index and one folder per LCSC part (datasheets and 3D models are fetched on demand, not redistributed) |
| `hw/out/` | Generated (git-ignored): Gerbers, BOM/CPL, KiCad file, case and assembly files |
| `cad/sphenix_hcal/` | `tile_params.json`, the original tile GDMLs, `scripts/fiber_loop.py` (the fiber-loop generator), `scripts/parse_inner_tile.py`, `scripts/export_mesh_json.py`, and one STEP per tile shape in `step/` |
| `sim/geant4/` | Geant4 tile model: `hcal_tile.cc` and `src/` (the `hcal_tile` program), `gdml/mesh/` (tile meshes and loops), `scripts/` (`run_tile.sh`, plots), `hcal_tiles_yield.json`. The older `muon_panel` program (the July 200 × 200 mm panel) still builds from the same CMake project and is not used |
| `sim/python/` | `coincidence_rates.py` (coincidence and accidental rates), `sipm_to_tot.py` (SiPM charge to time over threshold) |
| `figures/` | Geant4 result plots used in this README |
| `tools/memguard.sh` | Runs heavy jobs under a memory cap |
| `reference_documentation/` | Archived `muonTelescope` repositories, publications and earlier reviews |

The LaTeX paper, the July reports and charts, the Octave plots, the Vision Pro visualiser, the Google-Drive scripts and the July
panel renders were removed; `git log --diff-filter=D --name-only` finds them.

## License

See [LICENSE](LICENSE). Third-party datasheets and 3D models belong to their manufacturers. They are fetched on demand
(`cd hw && bun run parts`), not redistributed.

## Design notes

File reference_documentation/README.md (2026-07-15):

# Muon Telescope Reference and Documentation Archive

This directory consolidates the historical repositories, publications, prior design exports,
next-generation design package, and current review/requirements material.

## Directory map

- `repositories/` - all 28 cloned `muonTelescope` Git repositories; each `.git` history is preserved.
- `publications/` - locally archived public GSU and sPHENIX papers plus a publication index.
- `prior_design_exports/` - 2026 chat/decision exports, handoff material, and original package ZIP.
- `next_generation/` - unpacked KiCad, simulation, generator, and RP2350 reference artifacts.
- `review_and_requirements/` - current design review and the revised next-generation requirements.
- `working_files/` - temporary PDF renders and review intermediates retained for traceability.

The active starting points are:

1. `review_and_requirements/NEXT_GENERATION_REQUIREMENTS.md`
2. `review_and_requirements/NEXT_GENERATION_PCB_REVIEW.md`
3. `prior_design_exports/DECISIONS.md`
4. `next_generation/nextgen_review/hardware/README.md`

## External / collaborator reference simulations (phyxch)

Relevant public repositories from Xiaochun He (GSU) have been cloned under `repositories/` for offline reference and parameter cross-checks:

- `repositories/fiberPanel/` — GEANT4 simulation of scintillation light collection from a scintillator panel with embedded WLS fiber + SiPM. Direct prior/parallel art (straight-fiber position scans, detailed optical properties for EJ-200 / Y-11, Al wrapping, optical cement). Used for material definitions, surface modeling, photon counting approach, and yield scaling studies.
- `repositories/sPHENIX_HCal/` — standalone Geant4 + GDML geometry for sPHENIX Inner/Outer HCal tiles (originals retained). Muon3 builds STEP assemblies with fibers, light blockers, and coverings in `cad/sphenix_hcal/` and runs optical studies with `sim/geant4` target `hcal_tile`.
- `repositories/magnetocosmics/` — Cosmic-ray shower particle tracking through the geomagnetic field. Useful for future realistic primary generation (angular/energy spectra) beyond simple muon guns.

See the dedicated index `repositories/phyxch-references.md` for usage notes in the current analysis.

See also the local historical `repositories/scintillatorPanel/` (looped fiber CAD + assembly notes) and `publications/`.

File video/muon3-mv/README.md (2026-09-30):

# muon3-mv: the Muon3 music video

A Nordic hyperpop video that follows one cosmic-ray muon through every simulation in the repository
(Geant4 tile light, ngspice pulse chain, SiPM bias, board heat, Wi-Fi interference, tile stacking) and ends on the
gLowCost "Now" screen showing live data. 96 s, 1080p30, fframes (Rust + SVG), one generated SVG string per frame.

- Song: ElevenLabs Music, 168 BPM, `media/song.mp3`. Every cut sits on a bar line (`T_*` constants in `src/lib.rs`).
- Numbers: `tools/export_data.py` turns the repo's sim outputs into `src/data.rs` (fiber loop, 12 tile outlines,
  the ngspice pulse, the thermal field, tile-stack rates). The numbers in the text come from the project's README.
- The app screen (`src/app.rs`) is a redraw of the gLowCost-iOs "Now" screen with demo numbers.

```bash
cargo build --release
target/release/muon3_mv frame 40s,80s   # single frames
target/release/muon3_mv render          # out.mp4
```

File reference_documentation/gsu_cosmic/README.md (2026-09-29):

# GSU gLOWCOST / COSMIC web captures

These were captured on 2026-09-29 (Europe/Berlin) as sources for
`pcb/MUON3_MAX_SCOPE_ARCHITECTURE.md` §(a). That spec is no longer on `main`. It is preserved in commit `594b36c`
(`git show 594b36c:pcb/MUON3_MAX_SCOPE_ARCHITECTURE.md`) and was superseded by station Rev B
(see `hw/README.md` and D-2026-09-29b in `reference_documentation/prior_design_exports/DECISIONS.md`).

| File | Source |
|---|---|
| `gsu_index.txt` | Text of https://cosmic.gsu.edu/ |
| `glowcost-data.js` | Site/station data file served by https://cosmic.gsu.edu/ (22 sites, 11 countries) |
| `icrc2021.txt` | Text extract of ICRC 2021 proceedings, https://pos.sissa.it/395/1257/pdf |

These are third-party content, kept here for reference and traceability only.

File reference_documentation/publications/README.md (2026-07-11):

# Publication Index

## Locally archived

- `GSU_ICRC2019_Hybrid_Portable_Muon_Neutron_Detector.pdf` - He et al.,
  PoS(ICRC2019)078. Confirms three 20 x 20 x 1 cm scintillator panels with a glued circular
  WLS-fiber groove, a four-channel SiPM readout, 14 cm example panel spacing, coincidence
  plateau above about 54 V for the Hamamatsu generation, and about 120 paired-panel counts/min
  in the reported building configuration.
- `sPHENIX_2018_Design_and_Beam_Test.pdf` - Aidala et al., IEEE TNS 65 (2018),
  arXiv:1704.01461. Documents the sPHENIX calorimeter prototype lineage that motivated the
  GSU mechanical/scintillator work. Its calorimeter response is not a direct photoelectron-yield
  calibration for the GSU loop panel.

## Linked public reference

- Mubashir et al., “Muon Flux Variations Measured by Low-Cost Portable Cosmic Ray Detectors
  and Their Correlation With Space Weather Activity,” JGR Space Physics 128 (2023),
  DOI: https://doi.org/10.1029/2023JA031943

  The public mirror was unavailable during archival. The paper establishes pressure and
  temperature correction as core analysis requirements and compares identical GSU detectors
  in Atlanta and at Mount Wilson.

## Interpretation for the redesign

The publications validate the detector geometry, real-world count-rate scale, and network
science case. They do not provide a transferable, single-photoelectron-calibrated yield for the
current 20 cm loop-fiber panel with MicroFC-30035. The user's existing measured distributions
must therefore set the analog gain, threshold range, saturation target, and cooling benefit.

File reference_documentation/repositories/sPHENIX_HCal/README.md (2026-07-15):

# HCal 
This code is created for a quick test of detector geometry using gdml in GEANT4. 

For testing different geometry, one only needs to input a gdml file in GTDetectorConstruction.cc at 'parser.Read("xxx.gdml")'.

The stepping and primary generator actions are coded for very primative tests. Serious users should modify these for their specific needs.

The current code works well with Ubuntu 20.04 and multithreaded G4 simulation.

# Updated: March 9, 2024, Xiaochun He
1. Renamed the project from geomTest to HCal
2. The steering gdml file, which is read in by the geometry constructor, called sPHENIX_HCal.gdml. This means that one needs to link it to the real gdml file before running the simulation

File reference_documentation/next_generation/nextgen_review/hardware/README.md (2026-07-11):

# SiPM Muon Telescope — KiCad Project (KiCad 10)

Generated 2026-06-11. Four hierarchical sheets implementing the simulated TIA front-end design
(see the accompanying simulation report): 4× SiPM → OPA858 TIA → TLV3601 → iCE40UP5K-SG48,
TPS61170 HV boost + π filter + DAC trim + ADC readback, DAC7578 thresholds, BME280, W25Q128
config flash, TCXO, GNSS-module and nRF9151-carrier headers.

## Opening in KiCad 10

Open `muon_telescope_v10/muon_telescope.kicad_pro`. The schematic files are written in the
20250114 s-expression format with generator_version 9.0 — the exact format the KiCad 10.0
release ships its own demo projects in. KiCad 10 opens it natively (the official migration
path); on first save it re-stamps the files to the current 20260306 format. Every s-expression
token used was checked against KiCad 10.0's parser keyword list (eeschema/schematic.keywords,
branch 10.0), and the grammar was pattern-matched against reference files from the 10.0 source
tree.

`muon_telescope_v7/` contains a byte-equivalent-structure twin in KiCad 7 format. It exists
because this project was machine-generated and validated headlessly with kicad-cli 7.0.11:
SVG/PDF plots of all four sheets plus a full netlist export, with the connectivity of every
critical net checked programmatically (TIA feedback loops, all four CMPx→FPGA pins, shared
VBOT, DAC routing, HV trim/readback, PPS, config-flash SPI, nRF SPI, 1V2 core). The v10 set is
generated from the identical structure, so the electrical verification carries over.

## First steps after opening

1. Run ERC. Global-label connectivity is used throughout (machine-generated layout); expect
   only style-level warnings.
2. Annotation is pre-assigned and collision-free; re-annotate only if you restructure.
3. Tidy label positions to taste — symbols are placed on grid but some labels overlap.

## Libraries

- `muon_parts.kicad_sym` — project library, all symbols used. Also embedded in each sheet, so
  the schematics are self-contained.
- `JLCPCB-Kicad-Library/` — bundled subset (symbols + footprints) of
  https://github.com/CDFER/JLCPCB-Kicad-Library (MIT). sym-lib-table and fp-lib-table already
  point at it via ${KIPRJMOD}. Re-clone the upstream repo for 3D models and live stock data.

## Sourcing status (read before ordering)

CDFER basic/preferred parts with LCSC numbers embedded in symbol fields:
all 0402/0603 R and C values, BAV99 (C2500), SS510B 100V Schottky (C7420368), 100µH filter
inductor (C68035), AMS1117-3.3 (C6186), BME280 (C92489), W25Q128JVSIQ (C97521).

Pinout-verified from official KiCad library or TI datasheets, LCSC ID to confirm at order time
(extended parts): OPA858 (WSON-8), TLV3601 (SOT-23-5: 1=OUT 2=VEE 3=IN+ 4=IN− 5=VCC, TI
SNOSDB1E), TPS61170 (VSON-6: 1=FB 2=COMP 3=GND 4=SW 5=CTRL 6=VIN, TI SLVS789D), DAC7578
(TSSOP-16), iCE40UP5K-SG48ITR (QFN-48).

Marked VERIFY in-schematic before ordering: XC6206P122 1.2 V LDO pinout and LCSC number;
TCXO footprint/pinout vs the exact part chosen; the two placeholder LCSC numbers on
0402 1µF / 0603 10µF; DAC7578 I²C address for ADDR0=GND; iCE40 VPP_2V5-from-3V3 against the
current Lattice datasheet; all HV-node capacitors must be ≥50 V (C0G/film on HV_QUIET).

## Design notes carried from simulation

DC-coupled anode readout: SiPM anode sits at the TIA virtual ground (VBOT, 2.40 V), cathode at
HV_QUIET — no input coupling cap, no undershoot. HV ≈ VBOT + Vbr + Vov: ~32.4 V for
MicroFC-30035 as drawn; for Hamamatsu S13360 (~58 V) replace the boost stage, filter unchanged.
Rf=2 kΩ 1%, Cf=2.2 pF C0G → 24.4 mV/p.e., 52 MHz, 3 p.e. threshold = 74 mV below baseline.
Comparator output idles HIGH, pulses LOW (falling edge = event), matching firmware convention.

## Layout-critical items

Rf/Cf at the OPA858 pins, no plane under summing nodes; boost hot loop compact and far from
the four INA nodes; comparator output routing away from analog inputs; star HV_QUIET
distribution after C12; thermal pads (OPA858 pin 9, TPS61170 pin 7, iCE40 pin 49) to GND.

## Regenerating

`python3 gen_sch.py v9` (KiCad-10-ready) or `python3 gen_sch.py v7` (kicad-cli-7-validatable).
gen_symbols.py holds all pin maps with their provenance in comments.

## PCB (muon_telescope.kicad_pcb)

108 x 86 mm, 4-layer: F.Cu signal | In1 solid GND | In2 +3V3 plane | B.Cu GND pour.
Placement complete and DRC-clean (0 clearance / courtyard / hole violations); routing is
intentionally left open — unconnected-net DRC entries are the ratsnest. The board file is
KiCad 7 format; KiCad 10 opens and migrates it like the schematics.

Grounding / noise architecture baked into the file:
- ONE continuous ground domain. No split planes anywhere — return currents cannot be forced
  around a slot, which is the classic ground-loop generator. Partitioning is by placement.
- 31 GND stitching vias on a 9 mm grid keep F.Cu / In1 / B.Cu grounds at the same potential
  at RF, preventing the pour islands from becoming patch antennas.
- Per-channel rule areas (no copper pour, In1+In2+B.Cu) under each TIA summing node:
  keeps parasitic capacitance off the Cf node and leakage paths off the femtocoulomb input.
- Boost quarantine: TPS61170 hot loop bottom-right, >40 mm from the nearest summing node;
  In2 under the entire boost area is GND (priority fill), denying the 3V3 plane any
  capacitive pickup from the switch node directly beneath it.
- U.FL per channel at the board edge: CENTER = anode signal, SHIELD = HV bias. The shield is
  AC-grounded by C1 within ~6 mm of the connector, so it shields normally while DC-carrying
  the bias - one coax per SiPM, minimal loop area. Both shield legs of the BWIPX footprint
  are netted (the upstream CDFER symbol leaves pad 3 floating - fixed here).
- HV netclass (0.5 mm clearance, pattern HV_* + BOOST_SW) is defined in the .kicad_pro.

Routing order suggestion: (1) per-channel input: U.FL center -> R2 -> summing node -> OPA858
pin 3, with Rf/Cf to the FB pin, shortest possible, F.Cu only; (2) TIA -> comparator -> R5;
(3) CMPx to FPGA as spaced single-ended lines over solid In1; (4) HV_QUIET from C12 along the
bottom/left perimeter to the four R1s (DC, filtered - length is free); (5) boost hot loop
L1/U10/D10/C10 tight first, before anything else near it; (6) supplies last via In2 + drops.
Pad-local notes: thermal pads of U10/U101..U131/U3 need via farms to In1.

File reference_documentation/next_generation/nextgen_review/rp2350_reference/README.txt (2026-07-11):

Muon Telescope RP2040 Firmware + Web Serial Dashboard
====================================================

This project implements:
- 4-channel leading-edge capture (active-low pulses) on GPIO16..19
- Exact-subset coincidence clustering within a programmable window
- Per-period (default 60s) counts for:
  * Singles CH0..CH3
  * 2-fold exact subsets: 01,02,03,12,13,23
  * 3-fold exact subsets: 012,013,023,123
  * 4-fold exact subset: 0123
- BME280 readout over I2C (addr 0x77; SDO tied high) on GPIO4/5
- DAC7578 8-channel I2C DAC control (default addr 0x4C) on same I2C bus
- USB CDC (TinyUSB) binary framing suitable for Web Serial
- Command interface to configure window/holdoff/period and DAC codes

Build (pico-sdk)
----------------
1) Install pico-sdk and set PICO_SDK_PATH
2) From firmware/:
   mkdir build && cd build
   cmake ..
   make -j

Flash to RP2040 as usual (UF2 or SWD).

Pins
----
CH0..CH3: GPIO16..19 (active-low pulses; leading edge = falling edge)
I2C SDA: GPIO4
I2C SCL: GPIO5
MAX1932_INT: GPIO22 (optional fault flag input)

USB Protocol
------------
Frames are:
  A5 5A TYPE LENlo LENhi PAYLOAD... CRC16lo CRC16hi
CRC16-CCITT (0x1021, init 0xFFFF) over TYPE+LEN+PAYLOAD.

Device->Host report (TYPE 0x11) payload:
  u32 period_index
  u32 period_ms
  u16 window_ticks
  u16 holdoff_ticks
  u32 singles[4]
  u32 exact_subset[11] (masks: 3,5,9,6,10,12,7,11,13,14,15)
  i16 temp_c_x100
  u16 hum_rh_x100
  u32 press_pa
  u16 dac_code[8]
  u32 dropped_events
  u32 err_flags
  u32 uptime_ms

Host->Device command (TYPE 0x80) payload:
  u8 cmd_id, u8 seq, u16 arg_len, args...

Device->Host ACK (TYPE 0x81) payload:
  u8 cmd_id, u8 seq, u8 status, u8 reserved, u16 ret_len, ret...

Commands
--------
0x01 SET_REPORT_PERIOD_MS   args: u32 period_ms
0x02 SET_WINDOW_TICKS       args: u16 window_ticks
0x03 SET_HOLDOFF_TICKS      args: u16 holdoff_ticks
0x04 RESET_COUNTERS         args: none
0x10 DAC_SET_CH             args: u8 ch (0..7), u16 code (0..4095)
0x11 DAC_SET_ALL            args: u16 code0..code7
0x12 DAC_GET_ALL            args: none, returns u16 code0..code7
0x20 GET_STATUS             args: none, returns a copy of last report fields (without counters reset)

Dashboard
---------
Open dashboard/index.html in Chrome/Edge, click Connect, select the USB CDC port.
You can change report period (e.g. 1000ms for realtime graphs), window/holdoff ticks, and DAC outputs.

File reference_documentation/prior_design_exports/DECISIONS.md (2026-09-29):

# DECISIONS.md — Design Decisions & Reasoning
4-Channel SiPM Cosmic-Ray Muon Telescope. ADR-style log. Each entry: decision, alternatives
considered, reasoning, quantitative evidence, verification status, open items.

Status legend: [SIM] verified in ngspice · [NET] verified in exported KiCad netlist ·
[DRC] verified by pcbnew DRC · [DS] verified against datasheet/official source ·
[OPEN] decision or verification still pending.

---

## D1. Operate at 3–10 p.e. threshold, not single-photon
**Decision:** Nominal threshold 3 p.e. (2.326 V, i.e. 74 mV below 2.40 V baseline); keep
DAC reach down to 1–2 p.e. for calibration runs only.
**Alternatives:** 0.5–1 p.e. "single photon" operation (the original framing).
**Reasoning:** S13360-2050VE dark rate at 0.5 p.e. is O(100 kHz)/channel at room temp.
Accidental coincidences R1·R2·2τ ≈ 18 kHz for two 300 kHz channels at 100 ns — 6 orders
above the real muon rate (~1/min/cm²). Also a power win: kHz-not-100kHz event handling.
The single-p.e. staircase remains reachable purely as a gain-calibration observable.
**Evidence:** [SIM] 3 p.e. sits exactly at trigger edge in transient runs; electronics noise
0.06 p.e. rms → threshold is 48 σ from noise, so trigger rate is set by SiPM dark counts
alone. DAC LSB = 0.8 mV = 0.033 p.e.

## D2. Architecture: iCE40UP5K (timing) + nRF9151 (housekeeping + LTE-M); RP2350 dropped
**Decision:** Two-chip split. UP5K fabric: edge capture, coincidence windowing, exact-subset
counters, ToT histograms, holdoff, shadow-window engine, PPS counter latch — all in
BRAM-backed registers read by the nRF9151 over SPI. nRF9151 M33 (Zephyr): I2C (DAC7578,
BME280), boost trim/enable, ADC (HV_MON, NTCs), GNSS NMEA, batching + LTE-M uplink.
**Alternatives:** (a) keep RP2350 (PIO adequate but serial capture, FIFO/queue drop
pathology, tens of mA); (b) FPGA-only with soft core (USB/I2C in fabric painful);
(c) RP2350 + nRF9151-as-AT-modem (named as the fast-track fallback and v1→v2 path).
**Reasoning:** FPGA is strictly better at the 5% (deterministic parallel ns capture, µA–mA);
nRF9151's built-in M33 absorbs the 95% housekeeping the RP did, so nothing is duplicated.
Open-toolchain criterion (original reason for RP over FPGA) is satisfied by
yosys/nextpnr/icestorm.
**Power:** cellular TX bursts 100–300 mA are amortized by PSM + batching (15–60 reports per
uplink → <1 mA average; batching interval is an OTA knob). Flag/pause counting during TX
bursts (~0.1% deadtime) rather than risk RF-coupled fake coincidences. [OPEN] nRF9151 is
carried on headers (J7/J8) to a certified module/carrier — sourcing + exact carrier pin map
to be finalized; RF antenna keep-away from the analog strip.

## D3. Front end: DC-coupled anode-readout TIA (OPA858), replacing BFR93A discrete
**Decision:** Per channel: SiPM anode direct to OPA858 inverting input held at VBOT
(2.40 V virtual ground); cathode at HV_QUIET via 100 k + 100 n. Rf = 2 kΩ 1%,
Cf = 2.2 pF C0G. TIA output → TLV3601 IN+, threshold DAC → IN− ⇒ active-low output
(idle HIGH, event = falling edge), matching existing firmware convention.
**Alternatives considered in order:** BFR93A common-emitter (rejected: 140 pF into kΩ input
= µs pole); common-base BJT (viable: re ≈ 13 Ω @ 2 mA, recommended while power budget was
~1–2 mA/ch; BFP420/640 as modern parts); OPA855/LTC6268 (same class, rejected earlier purely
on power); SiPM ASICs (overkill). User raised ceiling to ~20 mA/ch → TIA chosen.
**Reasoning (TIA wins):** virtual ground makes the 140 pF a one-time compensation problem
(Cf), not a bandwidth killer; gain = Rf → four channels matched to 1% and temperature-flat,
so one DAC-code→p.e. constant serves all channels (prerequisite for threshold-scan
spectroscopy and ToT gain tracking); linear-to-rail with tens-of-ns overload recovery;
**DC coupling deletes the AC-coupling undershoot / rate-dependent-baseline problem
entirely** (dark current µA × 2 k = mV static offset only). OPA858 specifics: FET input
(no current noise into 2 k), decompensated min-gain-7 is safe because HF noise gain
1+Cin/Cf ≈ 66; the FB pin (pin 1) is an internal tie to OUT provided for tight Rf/Cf
routing — feedback connects there. [DS from official KiCad lib]
**Evidence:** [SIM] 24.4 mV/p.e.; f₋₃dB 52.5 MHz with 0.0 dB peaking at Cf = 2.2 pF
(1.0 pF → +3.6 dB peaking/ringing; 4.7 pF → 19 MHz overdamped) — matches hand calc
Cf = √(Cin/(π·Rf·GBW)) = 2.08 pF; linear to ~92 p.e.; 500 p.e. overload recovers ≈140 ns,
no re-trigger; time-walk 6.7 ns over 4→800 p.e.; output noise 1.5 mV rms (en·(1+Cin/Cf)·
√(1.57·f₋₃dB)), Rf Johnson 52 µV negligible. [NET] full feedback loop verified incl. FB pin.
**Fallback documented:** OPA356 (~8 mA): 11.8 mV/p.e., ~10 MHz, Cf = 11 pF, time-walk
19.1 ns — adequate for 50–100 ns windows; NOT pin-compatible → decide before layout freeze.
Macromodel caveat: op-amp/comparator models are datasheet-parameter macros (TI encrypted
models don't run in ngspice); edges good to ±20%, gain/stability/ToT-shape solid.

## D4. Comparator: TLV3601 (TLV3603 optional for pin-set hysteresis)
**Decision:** TLV3601 DBV per channel; 33 Ω series into FPGA pin. Pinout [DS]: 1 OUT, 2 VEE,
3 IN+, 4 IN−, 5 VCC. Internal hysteresis ~3–6 mV — never chatters against 24 mV/p.e.
**Correction made mid-project:** Icc is 4.9 mA typ (datasheet), not the ~1 mA first quoted.
4× ≈ 20 mA. If that matters, LMV7219 (1.1 mA, 7 ns) is the drop-back; kept TLV3601 for
2.5 ns and modern sourcing. [OPEN] revisit at power-budget close-out.

## D5. ToT as the energy observable; peak-detector path dropped
**Decision:** Capture both comparator edges in fabric, 10 ns bins; per-channel coarse ToT
histograms (16–32 bins) in BRAM, shipped with every report. No ADC peak detector.
**Reasoning:** ToT ≈ τ·ln(A/Vth) — logarithmic/compressed. Sufficient for: dark/afterpulse
rejection inside coincidences, gain drift tracking via muon ToT-peak position (a physics
closed loop on top of the thermometric one), corner-clipper tagging. NOT a muon energy
spectrometer — 1 cm scintillator gives Landau dE/dx nearly independent of muon momentum;
no estimator fixes that. Events above analog clip (~92 p.e.) classified "large", not read
as energy (sim showed compression + slight non-monotonicity in deep saturation).
**Evidence:** [SIM] ToT = 14.6·ln(Npe) − 7.5 ns fit over 4–75 p.e., slope ≈ SiPM decay τ.
**Upgrade path:** dual-threshold ToT (second comparator/channel; DAC spare channels exist).

## D6. SiPM choice: schematic drawn for MicroFC-30035; Hamamatsu remains an option [OPEN]
**Decision (provisional):** HV chain drawn for onsemi MicroFC-30035: HV_QUIET ≈ 29.8–32.4 V
(cathode−VBOT = Vbr+Vov; sim used 32.4 V placeholder — signal behavior depends only on
pulse charge). TPS61170 boost fits this directly.
**Reasoning:** Vbr ~24.5 V with few-hundred-mV matching (shared rail viable), 21.5 mV/°C
(≈⅓ the fractional drift), simple cheap boost replaces APD-specific MAX1932, CosmicWatch
heritage. Hamamatsu path preserved: swap boost stage (MAX1932 or higher-ratio), filter and
everything downstream unchanged; all sims used the Hamamatsu 140 pF (conservative — MicroFC
Cterm is smaller, only improves bandwidth). [OPEN] final SiPM selection; HV cap voltage
ratings must follow (≥50 V for MicroFC, ≥100 V margin for Hamamatsu).

## D7. HV bias: TPS61170 + π filter + DAC trim + ADC readback
**Decision:** VSYS → TPS61170 (pins [DS]: 1 FB, 2 COMP, 3 GND, 4 SW, 5 CTRL=EN_HV, 6 VIN
+ pad; external L1 10 µH ≥1.2 A, SS510B 100 V Schottky, COMP 4.7 k + 10 n) → C10 1 µ →
L2 100 µ (CDFER 2 mA part is fine: load is µA) → C11 1 µ → R10 1 k → C12 2.2 µ film/C0G →
HV_QUIET → per-channel 100 k + 100 n at each U.FL. FB divider 270 k/10 k sets ≈34.4 V;
R13 100 k from FB to HV_TRIM (DAC ch or filtered PWM) pulls setpoint down. Readback:
1 M/62 k (÷17.1) → HV_MON → nRF9151 ADC.
**Reasoning:** µA loads make brute-force RC filtering nearly free; setpoint must be
firmware-trimmable for the temperature loop (D8); readback closes the loop and separates
"boost died" from "no muons" remotely. X7R forbidden on the final HV node (DC-bias
capacitance collapse) — film/C0G specified.
**Evidence:** [SIM/analytic] ≥84 dB (R10/C12) + ≥98 dB (per-channel RC) at the 1.2 MHz
switch frequency; residual risk identified as MAGNETIC coupling from the hot loop → handled
by placement (D13), not filtering. [NET] HV_FB/HV_TRIM/HV_MON/EN_HV all verified.

## D8. Two nested gain-stabilization loops
**Decision:** (1) Thermometric: nRF9151 reads BME280 (+ per-SiPM NTCs on ADC), sets
V_bias = Vbr(25°) + tempco·(T−25) + Vov via HV_TRIM, ~1/min. (2) Physics: track the muon
ToT-distribution peak; drift = residual gain error → slow correction / flag.
**Reasoning:** SiPM gain ∝ overvoltage; NTCs on the SiPM carriers track die (not air)
temperature under solar load. The ToT peak is a free, continuous, physics-grounded
calibration that validates the datasheet tempco in situ.

## D9. Timing: LC76G GNSS PPS + TCXO-clocked FPGA, disciplined by arithmetic
**Decision:** LC76G on header J6 (3V3/GND/TX/RX/PPS/EN); PPS → iCE40 pin 20 (G3 global);
TCXO (±0.5–2 ppm, 2520, e.g. 25 MHz) → pin 35 (G0). Fabric latches the free-running counter
on each PPS edge; counter-delta-per-PPS goes in every report (= measured true oscillator
frequency and TCXO health). Timestamps disciplined in nRF9151 software — no PLL gymnastics.
UTC second label from NMEA over nRF9151 UART.
**Reasoning:** enables inter-station extensive-air-shower coincidence (HiSPARC/CREDO model);
PPS ±20–30 ns matches 10 ns bins; nRF9151's own GNSS lacks a hardware-precision PPS.
iCE40 has no crystal driver → oscillator mandatory; TCXO sets holdover quality if GNSS is
duty-cycled (~25 mA tracking is the biggest optional load). [OPEN] TCXO part selection —
footprint drawn as ECS 2520MV 4-pin, VERIFY pinout of the exact part ordered.

## D10. FPGA feature set (RTL scope for Codex)
Committed data-product features, all cheap in fabric: exact-subset coincidence counters
(15 masks, order 3,5,9,6,10,12,7,11,13,14,15 — exact-subset semantics: a 3-fold does NOT
increment its 2-fold subsets), raw singles, configurable window + holdoff (holdoff MUST be
bypassable for lifetime mode), per-channel ToT histograms, **shadow-window accidentals
engine** (clone coincidence engine, one channel delayed few µs → continuous measured fake
rate in every report), **muon-lifetime histogram** (same-channel double pulses 0.5–20 µs,
τ = 2.2 µs exponential), livetime/deadtime counters, PPS counter latch, charge-injection
pulse generator output (via ~1 pF into each preamp input — [OPEN] injection network not yet
in schematic), SPI slave register bank to nRF9151 (pins: SCK 23, COPI 25, CIPO 26, CS 27,
IRQ 28). Config from W25Q128 on hard SPI (SO 14, SCK 15, SS 16, SI 17; CRESET 8, CDONE 7).

## D11. Verified pin map (frozen by schematic, [NET])
iCE40UP5K-SG48: CMP0–3 = 9/10/11/12 (IOB_16a/18a/20a/22b); PPS = 20 (G3); TCXO = 35 (G0);
config flash 14/15/16/17; nRF SPI 23/25/26/27 + IRQ 28; RGB 39/40/41 (open-drain, LED
anodes via 100 Ω to 3V3); spares no-connected, to become test pads. Powers: VCC(5,30)=1V2;
VCCIO_0(33), SPI_VCCIO1(22), VCCIO_2(1), VCCPLL(29) = 3V3; VPP_2V5(24) = 3V3 [OPEN: VERIFY
against current Lattice DS — 2.3–3.6 V believed permitted]. DAC7578: VOUTA–D = THRESH0–3,
VOUTE = VBOT (ONE shared baseline for all four channels — identical by design, frees
channels), VOUTF = HV_TRIM, G/H spare; VREFIN = AVDD = 3V3 (ratiometric, LSB 0.8 mV);
~LDAC = GND, ~CLR = 3V3, ADDR0 = GND [OPEN: VERIFY resulting I2C address]. BME280:
CSB = SDO = 3V3 → I2C addr 0x77. I2C pull-ups 2×4.7 k.

## D12. U.FL SiPM interconnect: shield = HV, center = signal (user requirement)
**Decision:** One BWIPX-1-001E U.FL per channel at the board edge (CDFER, LCSC C5137195).
Center pin = SiPM anode → R2 10 Ω → summing node. Shield = HV_SIPMx = cathode bias.
**Reasoning:** the shield is AC-grounded by C1 100 n within ~6 mm of the connector → it
shields normally at signal frequencies while DC-carrying the bias; bias + signal share one
coax → minimal loop area, no separate bias lead to pick up fields. ~30 V DC on a touchable
shield is SELV; Hamamatsu variant (~58 V) still <60 V DC but flagged.
**Bug found & fixed:** CDFER's U.FL FOOTPRINT has pads 1/2/3 (two shield legs) but their
SYMBOL nets only pad 2 → one shield leg would float. Project symbol carries pin 3 = second
shield leg, netted to HV_SIPMx. [NET] HV_SIPM0 = {C101.1, J2.2, J2.3, R101.2};
SIPM_AN0 = {J2.1, R102.1}.

## D13. PCB grounding / noise architecture (the "no ground loops" answer)
**Decisions baked into muon_telescope.kicad_pcb (108×86 mm, 4-layer
F.Cu | In1 GND | In2 +3V3 | B.Cu GND):**
1. **ONE continuous ground domain — no split planes anywhere.** A plane slot forces return
   currents around it = the classic manufactured ground loop. Partitioning is achieved by
   PLACEMENT distance, not copper surgery.
2. 31 GND stitching vias on a 9 mm grid tie F/In1/B grounds to one RF potential (pours
   can't become patch antennas), auto-excluded from component bboxes and rule areas.
3. Per-channel RULE AREAS (no copper pour, In1+In2+B.Cu) under each summing node
   (Rf/Cf/INA region): protects the 2.2 pF Cf from plane parasitics and the fC-sensitive
   node from leakage. Stitching-via generator skips these.
4. **Boost quarantine:** TPS61170 hot loop bottom-right, >40 mm from the nearest summing
   node; In2 beneath the entire boost region is a priority GND fill — the 3V3 plane is
   denied any area under the switch node, so it can't capacitively pick up SW edges and
   carry them across the board.
5. Channels strip on the LEFT edge, U.FL at the edge, signal grows monotonically
   left→right (U.FL → R2 → clamps → TIA → comparator → 33 Ω → FPGA); comparator outputs
   (3.3 V/1 ns edges, the main self-interference source) route right, away from all INAs,
   over solid In1.
6. HV distribution: star from C12; HV_QUIET runs the bottom/left perimeter to the four R1s
   (DC + filtered → length free). HV netclass 0.5 mm clearance (patterns HV_*, BOOST_SW)
   in .kicad_pro.
7. Routing intentionally left manual, with ordered guidance in README (input paths first
   and shortest, boost hot loop tight before neighbors, supplies last via In2, via farms on
   all thermal pads). [OPEN] snug decoupling caps to supply pins during routing (currently
   ~4 mm).
**Evidence:** [DRC] final report: 0 clearance / 0 courtyard / 0 hole / 0 dangling-via /
0 mask-bridge; remaining entries = unrouted ratsnest (expected) + cosmetic silk.
Earlier DRC iterations caught and fixed: cross-sheet refdes collisions (see D15), header
rot-270 extent collisions, 16 mm channel pitch touching (→17 mm), mounting-hole conflicts.

## D14. File format strategy (KiCad 10 requirement)
**Decision:** Primary deliverable in 20250114 / generator 9.0 grammar — the exact format
KiCad 10.0 ships its own demo projects in (verified by pulling demos + sch_file_versions.h
from the 10.0 source branch; current native version is 20260306, stamped on first save).
Grammar pattern-matched element-by-element against 10.0-tree reference files; every emitted
s-expr token checked against eeschema/schematic.keywords from branch 10.0. A structurally
identical KiCad 7 twin exists because the only locally runnable validator is
kicad-cli 7.0.11 — the twin was netlist-validated and, being generated from identical
structure, transfers that verification to the v10 set. PCB is v7 format (KiCad 10 migrates
on open; official docs guarantee backward compatibility). CDFER footprints are v8-format →
a lossless-for-geometry v8→v7 down-converter (property→fp_text, uuid→tstamp, token
whitelist) produced JLCPCB_v7.pretty; original CDFER lib also bundled for KiCad 10 use.

## D15. Verification methodology (why the netlist step is non-negotiable)
Machine-generated EDA files were validated at four levels: (1) parser level (kicad-cli
plot/netlist for v7; sexpdata + token-vocabulary + keyword-list audit for v10 grammar);
(2) electrical level — programmatic assertions on every critical net in the exported
netlist; (3) DRC level for the board; (4) simulation level for the analog values the
schematic encodes. This process caught three real bugs that would otherwise have shipped:
duplicate refdes across sheets silently merging nets; the CDFER U.FL floating shield pad;
the op-amp macromodel wind-up masquerading as a latch-up. Lesson encoded for future agents:
never trust generated EDA artifacts without netlist-level assertions.

## D16. Consolidated OPEN items / VERIFY-before-order list
- Final SiPM selection (MicroFC-30035 vs S13360-2050VE) → boost stage + HV cap ratings.
- XC6206P122 1.2 V LDO pinout + LCSC ID; placeholder LCSC on 0402 1 µF / 0603 10 µF.
- DAC7578 I2C address for ADDR0=GND; TLV3601/OPA858/TPS61170/DAC7578/iCE40 extended-part
  LCSC IDs (live stock check).
- iCE40 VPP_2V5 fed from 3V3 vs current Lattice datasheet.
- TCXO exact part vs drawn ECS-2520MV footprint/pinout; GNSS LC76G module pin order on J6.
- nRF9151 carrier choice + J7/J8 pin agreement; antenna keep-away.
- Charge-injection network (D10) not yet in schematic.
- TLV3601 20 mA total vs LMV7219 4.4 mA — power close-out decision.
- AMS1117 (linear) → 3.3 V buck swap for the solar build.
- Routing pass; decouplers to pins; thermal-pad via farms; then ERC/DRC in real KiCad 10
  as final authority; JLC fab/BOM/CPL export.

## D17. Suggested next work packages (for Codex)
1. iCE40 RTL: register map + capture/coincidence/ToT/shadow/lifetime/PPS blocks per D10/D11
   (yosys/nextpnr, icebreaker-style constraints from the frozen pin map).
2. nRF9151 Zephyr firmware: SPI register client, I2C drivers (reuse Summary-B protocol
   framing over LTE-M instead of USB CDC), temperature loop, batching/PSM.
3. PCB routing per D13 guidance; then fab outputs.
4. Bench validation plan is in the design report §8 (charge injection 0.27 V ≈ 1 p.e.).

---

## D-2026-09-29. Max-scope architecture freeze (supersedes D2 and related entries)
**Decision:** The architecture was re-frozen on 2026-09-29 (decisions #1–#12). The full record (`pcb/MUON3_MAX_SCOPE_ARCHITECTURE.md`,
`pcb/key_parts_max_scope.csv`, `pcb/freeze_questions.md`) was removed from `main` and is preserved in commit `594b36c`
(e.g. `git show 594b36c:pcb/MUON3_MAX_SCOPE_ARCHITECTURE.md`). **Superseded by D-2026-09-29b (station Rev B).**
- **Controller:** ESP32-S3-WROOM-1U-N16 replaces the nRF9151 as controller. The nRF9151 is an optional LTE modem (Serial LTE Modem firmware, not fitted by default). RP2350/RP2040 and nRF54 are not used.
- **Readout:** iCE40UP5K timing is kept. The analog front end moves to a Panel-Head Board per SiPM, with LVDS over a Micro-Fit 3.0 2×12 harness.
- **Power:** TPS25751 + BQ25798 + an on-board 4S1P 18650 pack (BQ76907).
- **Radio and extras:** RAK3172 LoRa; external U.FL antennas; W5500 Ethernet option; secure boot / flash encryption / signed OTA.
**Reasoning:**
- GSU sites are networked indoor rooms, so Wi-Fi and USB should be first-class.
- The nRF9151 is JLC pre-order only.
- A 50 cm analog run next to TEC PWM is avoided.
- Power failures cause data gaps, so the board carries a UPS.
**Status:** [OPEN] Verification gates G-AFE/G-HV/G-PWR/G-BAT/G-ESPIO/G-FPGA-IO/G-SEC etc. (spec §j). Rev A KiCad/tscircuit predate this decision and must be reworked. **[SUPERSEDED]** by D-2026-09-29b.

---

## D-2026-09-29b. Station Rev B: 84 × 50 mm, 4-layer, USB-only (supersedes D-2026-09-29)
**Decision:** The station is a single 84 × 50 mm, 4-layer board, assembled by JLC on one side (commits 267a13f and
db3ec53, merged to `main` in 8afe8bd). The code is in `hw/`, and `hw/README.md` describes it.
- **Controller and timing:** ESP32-S3-WROOM-1-N8. Hit time stamps and time-over-threshold come from MCPWM
  capture (12.5 ns, both edges); PCNT counts singles; coincidences are done in firmware.
- **Front end:** 4× edge SMA (shell = SiPM bias via 47 kΩ, centre = anode) → OPA356 TIA → LMV7219. Two MCP4728
  DACs provide the per-channel bias trim (TIA baseline) and the thresholds.
- **Bias:** MC34063 boost + BSS123 + 150 µH + LL4148 with a 1 mH/1 µF filter. It is set by an RC-filtered ESP32
  PWM with a boot-safe low default, and read back on HV_MON.
- **Power:** USB-C 5 V only, feeding AMS1117 + TLV75733. There is no battery; a USB power bank is the UPS.
- **Sensors:** BME280, SC7A20H, STEMMA QT.
- **Assembly:** the SMA bottom tabs are unpasted, so assembly is one-sided.
- **Dropped:** the iCE40, 18650 cells + charger, LoRa, MAX1932, panel-head boards / LVDS harness, TEC, LTE/SIM,
  GNSS, USB-PD, Ethernet, OLED and microSD.

**Reasoning:** GSU sites are indoor, powered and networked, so every other feature had to earn its place. The
ESP32 timers are enough for minute/hourly rates and coincidences. The MC34063 costs ≈ $0.15 vs $6.09 for the MAX1932.
A smaller 4-layer, one-sided board cuts PCB and PCBA cost.

**Status:** [OPEN]
- Safety sign-off for the bias voltage on the exposed SMA shells.
- Verify the HV trim range and power-up behaviour with the real TRIM network. The design comment and the sim
  assume an ideal TRIM source.
- Re-run the cost estimate and get a JLC quote.
- Firmware.

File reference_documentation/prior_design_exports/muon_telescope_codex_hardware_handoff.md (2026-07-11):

# Codex Engineering Handoff: 4-Channel SiPM Muon Telescope

**Purpose of this file:**  
Provide a detailed engineering handoff for Codex covering the detector concept, hardware design ideas, decisions already made, proposed requirements, firmware/dashboard implications, and open validation tasks.

This is **not** an SBIR grant summary. It is an internal technical design/rationale document intended to help continue schematic, PCB, firmware, and dashboard development.

**Project name:** 4-Channel SiPM Cosmic-Ray Muon Telescope  
**Current controller module:** ColorEasyPico2-RP2350  
**Current primary data mode:** periodic rate/count reporting over USB CDC / Web Serial  
**Current pulse mode:** active-low comparator pulses, leading-edge counting only  
**Current coincidence mode:** exact-subset coincidence counting  

---

## 1. High-Level System Goal

Build a compact, low-cost, browser-accessible cosmic-ray muon telescope using:

- Plastic scintillator paddles
- Wavelength-shifting fiber light collection
- SiPM optical readout
- Four analog detection channels
- Low-noise high-voltage SiPM bias
- Per-channel RF preamplifier and comparator
- RP2350 PIO-based edge capture
- Exact-subset coincidence counting
- BME280 environmental monitoring
- DAC7578 programmable threshold/baseline control
- USB CDC / Web Serial dashboard

The system should be suitable for:

- Cosmic-ray muon rate measurements
- Educational detector demonstrations
- Long-duration environmental correlation studies
- Future solar/LiPo field deployment
- Later expansion to ToT, peak detection, or directional telescope modes

---

## 2. Current System Architecture

```text
Scintillator paddle
→ WLS fiber
→ SiPM
→ RF transistor preamp
→ fast comparator
→ RP2350 GPIO / PIO edge capture
→ exact-subset coincidence counting
→ USB CDC binary protocol
→ Web Serial dashboard
```

Supporting subsystems:

```text
VSYS / USB power
→ MAX1932 SiPM HV supply
→ filtered HV rail
→ per-channel HV isolation
→ SiPM bias
```

```text
3V3
→ BME280 environmental sensor
→ DAC7578 threshold/baseline DAC
→ comparator/reference logic
```

---

## 3. Detector Physics Design Assumptions

### Scintillator

Selected / assumed scintillator:

```text
EJ-200 plastic scintillator
```

Assumptions:

- Thickness: approximately 1 cm
- Light yield: approximately 10,000 to 11,000 photons/MeV
- Minimum-ionizing muon energy deposition: approximately 2 MeV/cm
- Generated photons per vertical muon through 1 cm: approximately 20,000 to 22,000 photons

### Optical Chain

Current optical concept:

```text
EJ-200 scintillator
→ 1 mm WLS fiber loop
→ direct optical coupling to SiPM
```

Design-level detected-signal assumption:

- Realistic detected signal: approximately 20 to 100 photoelectrons
- Working design point: approximately 30 photoelectrons

Rationale:

- 30 photoelectrons is large enough for threshold triggering.
- It is still small enough that noise, threshold, temperature, and bias stability matter.
- The analog front-end should not rely on raw MCU GPIO thresholds.

---

## 4. SiPM Selection and Implications

Selected SiPM:

```text
Hamamatsu S13360-2050VE
```

Assumed parameters:

- Breakdown voltage: approximately 53 V ± 5 V
- Operating voltage target: Vbr + approximately 3 V, roughly 56 V
- Temperature coefficient: approximately 54 mV/°C
- Terminal capacitance: approximately 140 pF
- Pixel count: 1584
- Approximate pixel capacitance: approximately 88 fF
- Pulse width: tens of ns

Design implications:

1. **Bias stability matters.**  
   SiPM gain is proportional to overvoltage. Small HV ripple or drift can modulate gain and dark rate.

2. **Temperature matters.**  
   Breakdown voltage changes with temperature. The BME280 is included partly to correlate rate/gain behavior with environment.

3. **Input capacitance is significant.**  
   The 140 pF terminal capacitance can slow edges and burden a weak front-end.

4. **Use a preamp + comparator.**  
   Direct MCU input triggering is not reliable enough for this detector.

---

## 5. Major Hardware Design Decisions

### Decision 1: Use MAX1932 for SiPM High Voltage

Selected high-voltage controller:

```text
MAX1932
```

Reasoning:

- Designed for APD/SiPM-style high-voltage bias use.
- More appropriate than an MCU-bit-banged boost converter.
- Supports cleaner, more stable HV generation.
- Better path to millivolt-level ripple/stability after filtering.

Intended HV path:

```text
VSYS
→ MAX1932
→ HV_RAW
→ pi filter / HV cleanup
→ HV_QUIET
→ per-channel RC isolation
→ SiPM bias nodes
```

Required follow-up:

- Confirm pi filter exists in schematic/PCB.
- Confirm four per-channel HV isolation resistors.
- Confirm four local SiPM bias capacitors.
- Measure HV ripple on assembled PCB.
- Verify channel-to-channel coupling.

---

### Decision 2: Use Discrete RF Transistor Preamplifier

Selected preamp concept:

```text
Infineon BFR93A RF transistor preamp per channel
```

Reasoning:

- Raw SiPM signal amplitude is small.
- SiPM capacitance is large enough to affect bandwidth.
- RF transistor preamp gives faster, cleaner pulses.
- Avoids complexity/stability risk of very high-speed op-amp designs.
- Low BOM cost and practical for assembly.

Per-channel signal path:

```text
SiPM
→ sense/coupling network
→ BFR93A preamp
→ fast comparator
→ RP2350 GPIO
```

Required follow-up:

- Validate pulse amplitude and shape with SiPM or pulse injection.
- Confirm comparator threshold range covers expected signals.
- Confirm preamp is stable with real PCB parasitics.
- Confirm no oscillation or excessive ringing.

---

### Decision 3: Use Fast Comparator Digitization

Comparator class:

```text
LMV7219-class fast comparator
```

Reasoning:

- Provides deterministic digital edges.
- Avoids relying on MCU Schmitt input behavior.
- Enables programmable threshold control.
- Can support future ToT by capturing both edges.

Current behavior:

```text
Comparator output is active-low.
Idle state: HIGH.
Event leading edge: falling edge.
Current firmware uses falling edges only.
```

Required follow-up:

- Add/verify hysteresis.
- Add small series resistor into MCU input, typically 22 to 47 ohm.
- Confirm active-low polarity in firmware and hardware.
- Validate threshold versus dark-rate curves.

---

### Decision 4: Use RP2350 PIO Instead of FPGA

Current controller module:

```text
ColorEasyPico2-RP2350
```

Reasoning:

- PIO can capture edges deterministically enough for configurable coincidence counting.
- Event rates are low enough for firmware-side clustering.
- Avoids FPGA complexity.
- Supports USB CDC/Web Serial easily.
- Open toolchain.

Original discussion used RP2040, but latest hardware uses RP2350. Codex should assume RP2350 unless asked otherwise.

Required follow-up:

- Ensure pico-sdk target/build files are correct for RP2350.
- Verify PIO program compatibility.
- Confirm USB CDC works with the selected board definition.
- Confirm GPIO pin mapping matches latest schematic.

---

### Decision 5: Use Exact-Subset Coincidence Counting

Requirement:

Count exact channel subsets, not inclusive “at least” combinations.

Example:

- A `CH0&CH1&CH2` event increments only `CH0&CH1&CH2`.
- It does not also increment `CH0&CH1`, `CH0&CH2`, or `CH1&CH2`.

Reasoning:

- Gives cleaner scientific interpretation.
- Avoids double-counting higher-fold events.
- Host software can derive inclusive counts later if desired.

---

### Decision 6: Use BME280 Environmental Monitoring

Sensor:

```text
BME280
```

I2C address:

```text
0x77
```

because SDO is tied high.

Reported values:

- Temperature
- Humidity
- Pressure

Reasoning:

- Temperature affects SiPM breakdown voltage and gain.
- Pressure affects cosmic-ray muon flux.
- Environmental metadata improves long-duration rate analysis.
- Useful for future compensation algorithms.

---

### Decision 7: Use DAC7578 for 8 Analog Setpoints

DAC:

```text
DAC7578
```

Purpose:

- Four comparator thresholds.
- Four baseline/bottom/reference setpoints.

Physical channel mapping from schematic should be treated as:

```text
DAC A / channel 0 → THRESH0
DAC B / channel 1 → CH0_VBOT
DAC C / channel 2 → THRESH1
DAC D / channel 3 → CH1_VBOT
DAC E / channel 4 → THRESH2
DAC F / channel 5 → CH2_VBOT
DAC G / channel 6 → THRESH3
DAC H / channel 7 → CH3_VBOT
```

Important note:

Earlier dashboard labels assumed all thresholds first, then all VBOTs. That should be corrected to match the physical DAC channel mapping above unless the schematic is changed.

Assumed DAC I2C address in generated firmware:

```text
0x4C
```

This must be verified from the actual ADDR pin strapping and DAC7578 datasheet.

---

### Decision 8: Use USB CDC + Web Serial

Communication mode:

```text
USB CDC ACM serial
```

Reasoning:

- Works with Chrome/Edge Web Serial.
- Avoids custom desktop software.
- Data rate is low.
- Binary framing with CRC is robust against arbitrary read chunking.

The browser dashboard should:

- Connect over Web Serial.
- Verify CRC.
- Display rates and environmental values.
- Graph data in near real time.
- Show error flags.
- Control report period, coincidence window, holdoff, and DAC outputs.

---

## 6. Final Pin Mapping

This is the latest intended mapping.

### I2C Bus

Used by BME280 and DAC7578.

| Signal | RP2350 GPIO | Module Pin |
|---|---:|---:|
| SDA | GPIO4 | pin 6 |
| SCL | GPIO5 | pin 7 |

### Comparator Inputs

Active-low comparator outputs. Falling edge is the event timestamp.

| Signal | RP2350 GPIO | Module Pin |
|---|---:|---:|
| CH0 | GPIO16 | pin 21 |
| CH1 | GPIO17 | pin 22 |
| CH2 | GPIO18 | pin 24 |
| CH3 | GPIO19 | pin 25 |

### MAX1932 Control / Serial Interface

The SPI-like pins were moved because physical pin 30 is RUN and not a GPIO.

| Signal | RP2350 GPIO | Module Pin |
|---|---:|---:|
| MOSI | GPIO20 | pin 26 |
| SCLK | GPIO21 | pin 27 |
| MAX1932_INT | GPIO22 | pin 29 |
| MAX1932_SS | GPIO26 | pin 31 |

Important:

- Do not use RUN as GPIO.
- RUN is reset/run only.
- If MAX1932 control is not yet implemented in firmware, reserve these pins for it.

### Recommended LED / Button GPIOs

| Function | Suggested GPIO |
|---|---:|
| LED4-R | GPIO6 |
| LED4-G | GPIO7 |
| LED4-B | GPIO8 |
| LED5-R | GPIO9 |
| LED5-G | GPIO10 |
| LED5-B | GPIO11 |
| SW3 | GPIO12 |
| SW4 | GPIO13 |

LED recommendation:

```text
GPIO → resistor → LED → GND
```

Button recommendation:

```text
GPIO → button → GND
```

Use internal pull-ups for buttons.

---

## 7. Power Pin Decisions and Requirements

### VBUS

- USB 5 V rail.
- Present when USB cable is connected.
- Not regulated to 3.3 V.
- Should not be treated as a general clean analog supply.

### VSYS

Current intent:

```text
USB powers the module
→ module internal path provides VSYS
→ VSYS feeds MAX1932 input
```

This is acceptable if current limits are respected.

Schematic clarity requirement:

- If VSYS is being used as an output from the module, label it `VSYS` or `VSYS_TO_HV`.
- Avoid labeling it simply `+5V` if that implies an externally forced supply.

Future battery/solar mode:

```text
Solar charger / power-path output
→ VSYS
→ module regulator
→ 3V3
```

### 3V3

- Output of module onboard 3.3 V regulator.
- Use for BME280, DAC7578, low-voltage logic, and possibly comparator logic.
- Do not externally drive 3V3.

### 3V3_EN

- Regulator enable.
- Leave pulled high unless a deliberate shutdown circuit is added.
- Pulling low disables 3.3 V rail.

### RUN

- Reset/run pin.
- Pull low to reset RP2350.
- Not GPIO.

### VREF

- ADC reference input.
- Currently unused.
- Reserve for future precision ADC use if battery monitoring or peak measurement is implemented.

---

## 8. Firmware Requirements

### 8.1 Edge Capture

Inputs:

```text
GPIO16 → CH0
GPIO17 → CH1
GPIO18 → CH2
GPIO19 → CH3
```

Pulse polarity:

```text
active-low
leading edge = falling edge
```

Requirement:

- Capture falling-edge timestamps only for current release.
- No ToT required yet.
- Use PIO where possible.

### 8.2 Counting

Each report interval must include:

Raw singles:

```text
CH0
CH1
CH2
CH3
```

Exact 2-fold coincidences:

```text
CH0&CH1
CH0&CH2
CH0&CH3
CH1&CH2
CH1&CH3
CH2&CH3
```

Exact 3-fold coincidences:

```text
CH0&CH1&CH2
CH0&CH1&CH3
CH0&CH2&CH3
CH1&CH2&CH3
```

Exact 4-fold coincidence:

```text
CH0&CH1&CH2&CH3
```

### 8.3 Mask Definitions

Use 4-bit masks:

```text
bit0 = CH0
bit1 = CH1
bit2 = CH2
bit3 = CH3
```

Mask values:

```text
CH0 = 1
CH1 = 2
CH2 = 4
CH3 = 8

CH0&CH1 = 3
CH0&CH2 = 5
CH0&CH3 = 9
CH1&CH2 = 6
CH1&CH3 = 10
CH2&CH3 = 12

CH0&CH1&CH2 = 7
CH0&CH1&CH3 = 11
CH0&CH2&CH3 = 13
CH1&CH2&CH3 = 14

CH0&CH1&CH2&CH3 = 15
```

Report subset masks in this order:

```text
3, 5, 9, 6, 10, 12, 7, 11, 13, 14, 15
```

### 8.4 Cluster Algorithm

Use a cluster-based coincidence algorithm.

For each edge event `(ch, timestamp)`:

1. Increment raw singles count for `ch`.
2. If no cluster is active, start one.
3. If cluster is active and `timestamp - cluster_tmin <= window_ticks`, merge the channel into the cluster.
4. If outside the window, close the previous cluster, increment `subset_counts[cluster_mask]`, then start a new cluster.
5. At each report boundary, flush any active cluster.

Coincidence condition:

```text
max(t_i) - min(t_i) <= window_ticks
```

Use configurable holdoff:

```text
holdoff_ticks
```

to avoid duplicate clusters from ringing or afterpulsing.

Implementation caution:

- Events drained from four separate PIO FIFOs may not be globally timestamp-sorted.
- If synthetic tests reveal misclassification, add a small timestamp-sorted merge buffer before clustering.
- Timestamp wrap handling must be robust.

### 8.5 Report Period

Default:

```text
60,000 ms
```

Dashboard should allow changing report period to:

```text
1,000 ms to 5,000 ms
```

for real-time graphing.

### 8.6 BME280

Firmware must:

- Initialize BME280 at I2C address `0x77`.
- Read temperature, humidity, and pressure once per report interval.
- Include values in each report packet.
- Set an error flag if read fails.

### 8.7 DAC7578

Firmware must:

- Initialize DAC7578 on I2C.
- Support setting one DAC channel.
- Support setting all eight DAC channels.
- Cache current DAC codes.
- Include all eight DAC codes in every report packet.
- Use physical channel mapping matching the schematic.

### 8.8 MAX1932 Interface

Firmware should reserve and eventually implement:

```text
MOSI → GPIO20
SCLK → GPIO21
SS   → GPIO26
INT  → GPIO22
```

Current minimum requirement:

- Configure `MAX1932_INT` as input.
- Latch/report fault/interrupt state in error flags.

Future requirement:

- Implement MAX1932 programming/control if needed by the selected operating mode.

---

## 9. USB Protocol Requirements

Use binary framed USB CDC packets.

Frame format:

```text
SOF0 SOF1 TYPE LENlo LENhi PAYLOAD CRC16lo CRC16hi
0xA5 0x5A
```

CRC:

```text
CRC16-CCITT over TYPE + LEN + PAYLOAD
```

### Device-to-Host Report Packet

Type:

```text
0x11
```

Payload:

```text
u32 period_index
u32 period_ms
u16 window_ticks
u16 holdoff_ticks

u32 singles[4]

u32 exact_subset[11]
  order: masks 3,5,9,6,10,12,7,11,13,14,15

i16 bme_temp_c_x100
u16 bme_hum_rh_x100
u32 bme_press_pa

u16 dac_code[8]

u32 dropped_events
u32 err_flags
u32 uptime_ms
```

### Host-to-Device Command Packet

Type:

```text
0x80
```

Payload:

```text
u8  cmd_id
u8  seq
u16 arg_len
u8  args[arg_len]
```

### Device-to-Host ACK Packet

Type:

```text
0x81
```

Payload:

```text
u8  cmd_id
u8  seq
u8  status
u8  reserved
u16 ret_len
u8  ret[ret_len]
```

### Commands

Required commands:

| Command | ID | Args | Purpose |
|---|---:|---|---|
| SET_REPORT_PERIOD_MS | 0x01 | u32 period_ms | Change report interval |
| SET_WINDOW_TICKS | 0x02 | u16 window_ticks | Change coincidence window |
| SET_HOLDOFF_TICKS | 0x03 | u16 holdoff_ticks | Change cluster holdoff |
| RESET_COUNTERS | 0x04 | none | Clear counts and restart period |
| DAC_SET_CH | 0x10 | u8 ch, u16 code | Set one DAC output |
| DAC_SET_ALL | 0x11 | u16 code[8] | Set all DAC outputs |
| DAC_GET_ALL | 0x12 | none | Return cached DAC codes |
| GET_STATUS | 0x20 | none | Return status/config summary |

Recommended future commands:

| Command | Purpose |
|---|---|
| CLEAR_ERRORS | Clear latched error flags |
| SET_DAC_LABEL_MAP | Optional host-defined DAC labels |
| GET_VERSION | Firmware/hardware/protocol version |
| SAVE_CONFIG | Persist config to flash |
| LOAD_DEFAULTS | Restore defaults |
| SET_LED_MODE | Configure status LEDs |
| GET_RAW_DEBUG | Enable temporary diagnostic event stream |

---

## 10. Error Flags

Use a 32-bit error flag field in report packets.

Recommended current bits:

```text
bit0 = PIO/event queue dropped event
bit1 = USB TX backlog
bit2 = BME280 read/init failure
bit3 = DAC7578 write/init failure
bit4 = I2C recovery invoked
bit5 = MAX1932_INT asserted
bit6 = RX CRC error
bit7 = RX framing/command parse error
```

Dashboard should decode and display these in human-readable form.

---

## 11. Web Dashboard Requirements

The browser dashboard should use Web Serial.

### Required UI Features

Connection/status:

- Connect/disconnect button.
- Show last packet age.
- Show packet count.
- Show CRC error count.
- Show dropped events.
- Show error flags.

Configuration controls:

- Report period in ms.
- Coincidence window in ticks.
- Holdoff in ticks.
- Reset counters command.

DAC controls:

- Eight DAC sliders/numeric inputs.
- Correct labels matching schematic:
  - DAC A / 0 = THRESH0
  - DAC B / 1 = CH0_VBOT
  - DAC C / 2 = THRESH1
  - DAC D / 3 = CH1_VBOT
  - DAC E / 4 = THRESH2
  - DAC F / 5 = CH2_VBOT
  - DAC G / 6 = THRESH3
  - DAC H / 7 = CH3_VBOT
- Apply single channel.
- Apply all.
- Read back cached DAC values.

Live display:

- Latest singles counts and rates.
- Latest exact coincidence counts and rates.
- Derived total 2-fold rate.
- Derived total 3-fold rate.
- 4-fold rate.
- Temperature.
- Humidity.
- Pressure.

Graphing:

- Plot singles rates over time.
- Plot 2-fold total over time.
- Plot 3-fold total over time.
- Plot 4-fold over time.
- Plot environmental values over time or in separate plots.

Issue detection:

- Warn if no packet for more than 3 report periods.
- Warn if dropped event counter increases.
- Warn if any error flag is nonzero.
- Warn if BME280 read fails.
- Warn if DAC write fails.
- Warn if MAX1932_INT is asserted.

---

## 12. Existing Generated Firmware/Dashboard Zip Notes

A prior zip was generated:

```text
muon_telescope_project.zip
```

It included:

```text
README.txt
firmware/
  CMakeLists.txt
  pico_sdk_import.cmake
  pio/edge_fall.pio
  src/main.c
  src/proto.c/h
  src/bme280.c/h
  src/dac7578.c/h
dashboard/
  index.html
```

Important corrections Codex should apply before using it as final:

1. **RP2350 target**  
   The project may still be RP2040/pico-sdk generic. Update CMake/board target for ColorEasyPico2-RP2350.

2. **MAX1932 pins**  
   Ensure these final defines are used:
   ```c
   #define PIN_SPI_MOSI     20
   #define PIN_SPI_SCLK     21
   #define PIN_MAX1932_INT  22
   #define PIN_MAX1932_SS   26
   ```

3. **DAC labels**  
   Update dashboard labels to match physical DAC channel order:
   ```text
   A/0 = THRESH0
   B/1 = CH0_VBOT
   C/2 = THRESH1
   D/3 = CH1_VBOT
   E/4 = THRESH2
   F/5 = CH2_VBOT
   G/6 = THRESH3
   H/7 = CH3_VBOT
   ```

4. **DAC address**  
   Verify `0x4C`.

5. **BME280 address**  
   Use `0x77`.

6. **Cluster sorting**  
   Verify clustering correctness when events arrive from different PIO FIFOs.

7. **CRC and command ACK handling**  
   Dashboard should handle ACK packets visibly and report command errors.

8. **Clear errors command**  
   Add command to clear latched error flags.

---

## 13. Proposed Hardware Requirements

### 13.1 Detector Inputs

- Four SiPM inputs.
- Each channel supports Hamamatsu S13360-2050VE.
- Each channel should include proper bias feed and signal extraction.
- Each channel should include RF preamp and comparator.

### 13.2 HV Requirements

- Generate approximately 56 V SiPM bias.
- Bias adjustable/configurable if possible.
- Low ripple after filtering.
- Per-channel isolation.
- Safe discharge path for HV capacitors.
- Test points for HV_RAW, HV_QUIET, and at least one channel bias node.
- Appropriate creepage/clearance for 56 V and production margin.

### 13.3 Analog Front-End Requirements

- Four identical channels.
- Comparator outputs active-low.
- Hysteresis included or supported.
- DAC thresholds routed cleanly.
- Comparator output series resistors to MCU.
- Analog layout kept away from LEDs, USB, and switching nodes.

### 13.4 Digital Requirements

- RP2350 module with USB connection.
- GPIO16-19 reserved for comparator inputs.
- GPIO4/5 reserved for I2C.
- GPIO20/21/22/26 reserved for MAX1932.
- GPIO6-13 available for LEDs/buttons.

### 13.5 I2C Requirements

- BME280 and DAC7578 share I2C bus.
- Pull-ups sized appropriately for bus capacitance, commonly 2.2k-10k depending on layout.
- Route I2C away from sensitive analog input if possible.
- Provide test pads if space allows.

### 13.6 DAC Requirements

- Eight DAC outputs routed to thresholds and VBOT/reference nodes.
- DAC reference/supply decoupled cleanly.
- Output filtering may be added if comparator threshold noise is problematic.
- Verify output voltage range matches comparator threshold needs.

### 13.7 UI / Controls Requirements

- At least two buttons and two RGB/status LEDs are useful but optional.
- LEDs must include resistors.
- Buttons use pull-ups and switch to ground.
- LED currents should not return through analog front-end ground paths.

### 13.8 Power Requirements

USB-powered mode:

```text
USB → module → VSYS → MAX1932
USB → module regulator → 3V3 → sensors/DAC/logic
```

Future solar/LiPo mode:

```text
Maxeon 125 mm solar cell
→ solar LiPo charger / power-path manager
→ LiPo
→ VSYS
→ module 3V3 regulator
```

Do not back-power 3V3.

---

## 14. Proposed PCB Layout Requirements

Critical layout priorities:

1. **SiPM to preamp path must be short.**
2. **Preamp input node must be guarded from digital noise.**
3. **Comparator threshold/reference traces should be quiet.**
4. **MAX1932 switching loop should be compact and isolated.**
5. **HV filtering should be physically near MAX1932 output and SiPM distribution.**
6. **Per-channel HV RC isolation should be near each SiPM or bias branch.**
7. **Comparator outputs to RP2350 should be short and not routed near analog inputs.**
8. **LED/button currents should stay on the digital side.**
9. **Use solid ground plane where possible, with careful analog return planning.**
10. **Do not route switching regulator or LED currents under SiPM/preamp nodes.**

Recommended placement order per channel:

```text
SiPM connector/pad
→ preamp components
→ comparator
→ RP2350 input pin
```

Recommended power placement:

```text
VSYS entry / module
→ MAX1932 input decoupling
→ MAX1932 switching components
→ HV filter
→ HV distribution
```

---

## 15. Validation and Test Requirements

### 15.1 Bring-Up Tests

Before connecting SiPMs:

1. Verify 3V3 rail.
2. Verify VSYS rail.
3. Verify I2C bus scan sees BME280 and DAC7578.
4. Verify DAC outputs with multimeter.
5. Verify BME280 readings.
6. Verify USB CDC/Web Serial connection.
7. Verify command/ACK protocol.
8. Inject synthetic active-low pulses into CH0-CH3.
9. Verify singles and exact coincidence counts.
10. Verify MAX1932 disabled/safe state before HV test.

### 15.2 HV Tests

1. Power MAX1932 with no SiPM load.
2. Confirm HV output range.
3. Measure HV ripple before/after filter.
4. Verify safe discharge.
5. Verify per-channel HV nodes.
6. Confirm no unexpected coupling into comparator outputs.

### 15.3 Detector Tests

1. Connect SiPMs with conservative thresholds.
2. Sweep threshold and record dark rate.
3. Record singles in dark/covered condition.
4. Record scintillator muon singles.
5. Test 2-fold coincidences with stacked paddles.
6. Compare rates versus expected cosmic-ray geometry.
7. Record rate versus temperature/pressure.

### 15.4 Firmware Tests

Synthetic pulse tests should cover:

- Each individual channel.
- Each exact 2-fold combination.
- Each exact 3-fold combination.
- 4-fold combination.
- Pulses just inside the window.
- Pulses just outside the window.
- Rapid repeated pulses.
- Timestamp wrap if practical.
- High-rate event drop behavior.

---

## 16. Open Design Questions

Codex should not assume these are finalized unless the schematic confirms them.

1. Does the MAX1932 output include the intended pi filter?
2. Are all four per-channel HV isolation RC networks present?
3. What is the final DAC7578 I2C address?
4. What is the final DAC channel-to-net mapping?
5. Is comparator hysteresis implemented, and at what level?
6. Are comparator outputs truly active-low on final hardware?
7. Are there series resistors between comparator outputs and RP2350 inputs?
8. Is the RP2350 board target defined correctly in firmware?
9. Are LEDs/buttons assigned exactly as suggested or changed?
10. Will future solar/LiPo power be included on this PCB or later revision?
11. Are there test points for HV, DAC outputs, comparator outputs, I2C, and power rails?
12. Is there a safe HV discharge path?

---

## 17. Near-Term Codex Task List

Recommended immediate tasks:

1. Update firmware pin defines to final RP2350 mapping.
2. Update dashboard DAC labels to physical DAC channel order.
3. Add `CLEAR_ERRORS` command.
4. Add visible command ACK/error display in dashboard.
5. Add derived totals:
   - total exact 2-fold
   - total exact 3-fold
   - exact 4-fold
6. Add environmental graphs.
7. Confirm or improve PIO timestamp/cluster ordering.
8. Add unit tests or host-side simulator for exact-subset counting.
9. Add build instructions specifically for ColorEasyPico2-RP2350.
10. Add a hardware bring-up checklist to README.
11. Add constants for BME280 address `0x77` and DAC7578 address placeholder.
12. Add compile-time firmware version and protocol version packet.

---

## 18. Current Definition of Done for First Working Prototype

A first successful prototype should demonstrate:

1. USB powers the board.
2. VSYS powers MAX1932 input safely.
3. 3V3 powers logic, BME280, and DAC7578.
4. BME280 reports plausible temperature, humidity, and pressure.
5. DAC outputs all eight programmed setpoints.
6. Comparator outputs can be injected or triggered.
7. RP2350 counts active-low falling edges on CH0-CH3.
8. Exact-subset coincidence counts are correct.
9. Web Serial dashboard connects reliably.
10. Dashboard can change report period/window/holdoff.
11. Dashboard can set DAC channels.
12. Report packet includes counts, BME280, DAC codes, dropped events, error flags, and uptime.
13. No event drops at expected detector rates.
14. SiPM HV is stable and low-ripple enough for threshold triggering.
15. Muon coincidences can be observed with stacked scintillator paddles.

---

## 19. Summary of Latest Design State

The project is currently defined as:

```text
A 4-channel SiPM cosmic-ray muon telescope using EJ-200 scintillator,
WLS fiber, Hamamatsu S13360-2050VE SiPMs, MAX1932 HV bias,
BFR93A RF preamps, fast active-low comparators, ColorEasyPico2-RP2350
PIO edge capture, BME280 environmental sensing, DAC7578 programmable
threshold/baseline control, and USB CDC/Web Serial reporting.
```

Current data product:

```text
Periodic report with:
- raw singles CH0-CH3
- exact 2-fold subset counts
- exact 3-fold subset counts
- exact 4-fold subset count
- temperature
- humidity
- pressure
- DAC setpoints
- dropped event count
- error flags
- uptime
```

Current most important engineering risks:

```text
HV ripple/noise
analog front-end stability
comparator threshold noise
PIO event ordering
DAC channel mapping mismatch
RP2350 SDK/board target details
real-world SiPM dark rate and temperature behavior
```

Most important next action:

```text
Finalize schematic pin/net consistency, then bring up firmware with synthetic pulses
before connecting SiPMs and enabling HV.
```

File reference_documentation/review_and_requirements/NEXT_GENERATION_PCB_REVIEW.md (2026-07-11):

# Muon Telescope Next-Generation PCB Review

Date: 2026-07-11

> Requirements update: the production baseline is now MicroFC-30035 with 200 x 200 x 10 mm
> loop-fiber panels, directly integrated nRF9151-LACA cellular control, USB-C PD power, dual-threshold ToT plus
> per-channel baseline DACs, safe separated SiPM interconnects, and four independently controlled
> TEC/Peltier channels. See `NEXT_GENERATION_REQUIREMENTS.md` for the controlling specification.

## Scope and confidence

This review covers all 28 `muonTelescope` repositories, their first-party tracked files, README/documentation sources, condensed Git histories, the 2017 compiled technical manual, the 2026 chat/decision record, the RP2350 reference firmware archive, and the unpacked next-generation KiCad/simulation package in `nextgen_review/`. Vendor libraries and binary CAD models were inventoried and sampled where relevant; they were not treated as project decisions. The public gLOWCOST and Muon Telescope sites were also reviewed.

The review is design-level, not a fabrication sign-off. No KiCad or ngspice executable is installed locally. The supplied validation claims were therefore audited through their inputs, generated files, schematics, board structure, models, and current manufacturer documentation. The board has placement and zones but no routed track segments.

## Executive conclusion

The scientific/system concept is viable, and the broad architecture is sensible: a deterministic FPGA timing plane plus a cellular MCU/control plane is a good fit for a distributed detector network. The DC-coupled TIA concept, programmable thresholds, HV telemetry, GNSS PPS, exact-subset counters, ToT histograms, shadow-window accidentals, and remote calibration are all valuable.

The current Rev A package is not electrically viable or fabrication-ready. Two schematic errors alone are release blockers:

1. The OPA858 is supplied from 3.3 V while its inputs are biased at 2.40 V. TI specifies an input common-mode ceiling 1.4 V below the positive supply, or about 1.9 V at 3.3 V. The proposed operating point is out of specification, and the behavioral SPICE model does not model this limitation.
2. The iCE40UP5K `VCCPLL` supply is connected to 3.3 V. Lattice specifies 1.14-1.26 V recommended and 1.42 V absolute maximum. This can damage the FPGA.

The PCB contains 111 footprints, 31 stitching vias, nine zones, and zero routed segments. Existing DRC statements establish placement clearance, not a buildable or signal-integrity-validated board.

## Project history and decisions

### 2015-2017 modular generation

- The detector used roughly 145 x 145 x 10 mm EJ-200 tiles, a looped 1 mm WLS fiber, reflective/light-tight wrapping, and Hamamatsu S13360-2050VE SiPMs.
- The sensor board placed the SiPM, OPA846 preamplifier, 100 kOhm NTC, and optical test LED together. Git history records oscillation fixes, impedance matching, ground vias, sensor changes, and multiple fabricated revisions.
- Bias was per-channel using MAX1932 daughterboards, high-resolution voltage/temperature readback, closed-loop temperature correction, and independent monitoring. A batch of 24 HV boards was built.
- A Raspberry Pi-side stack handled GPIO coincidences, I2C control, environmental/GPS sensors, MySQL storage, REST APIs, and a web display. This software is useful historical evidence but is now technically obsolete (WiringPi, old Node/Bower/Polymer, old Docker/MySQL assumptions, embedded example credentials).

### 2019-2025 integrated interface generation

- `mppcInterface` moved to KiCad, combined MAX1932 bias, DAC control, an iCE40, Raspberry Pi headers, and an eight-channel analog design.
- The latest gateware is experimental, not production logic: it uses signal-derived clocks, 8-bit counters, combinational coincidences, unsynchronized asynchronous inputs, partial channel implementation, and debug UART behavior. It must not be reused as the next-generation timing core.
- The repository history documents useful practical lessons: negative-rail/inverter changes, ground-plane fixes, added decoupling, test points, I2C pin swaps, and repeated routing/fabrication iterations.

### 2026 redesign decisions

- Four channels, nominal 3 p.e. threshold; single-p.e. operation retained only for calibration.
- iCE40UP5K for deterministic edge/ToT/coincidence capture; nRF9151 for housekeeping and LTE-M/NB-IoT.
- DC-coupled anode-readout TIA using OPA858, 2 kOhm feedback and 2.2 pF compensation; TLV3601 comparator.
- Provisional switch from Hamamatsu S13360-2050VE to onsemi MicroFC-30035 to reduce HV and temperature coefficient.
- TPS61170 boost with DAC trim/readback, per-channel RC filtering, BME280 plus local NTCs, external GNSS PPS and TCXO.
- Exact-subset counters, ToT distributions, shadow-window accidentals, muon-lifetime mode, livetime/deadtime, and charge injection.
- One continuous ground system with placement-based partitioning, no-pour regions at summing nodes, and boost quarantine.

These are reasonable objectives, but several are recorded as decisions without corresponding implemented circuitry or RTL.

## Release blockers

### B1 - OPA858 common-mode violation

The schematic powers every OPA858 from 3.3 V and sets `VBOT = 2.40 V`. The current TI OPA858 data sheet specifies the upper input common-mode limit as 1.4 V below the positive rail. The provided macromodel models gain, poles, slew, and approximate output clamps but omits input common-mode behavior, shutdown behavior, bias current, power, supply sensitivity, and realistic overload states. Consequently, its gain/ToT results do not validate the chosen DC operating point.

Resolve by either:

- powering the OPA858 from a clean 5 V analog rail while preserving a 2.4 V baseline;
- lowering VBOT and thresholds to a valid 3.3 V operating point, then rechecking output swing, clamp behavior, DAC range, SiPM bias, and linear range; or
- selecting a truly rail-to-rail-input TIA-compatible amplifier and redoing stability/noise/overload analysis with an official model and bench prototype.

### B2 - iCE40 VCCPLL overvoltage

`gen_sch.py` groups `VCCPLL` with the 3.3 V I/O supplies. Lattice requires VCCPLL at the 1.2 V core level and recommends an RC noise filter between VCC and VCCPLL. Fix the symbol-to-rail mapping, add the required filter/decoupling, and audit every power pin against the current package table.

`VPP_2V5 = 3.3 V` is acceptable for Master SPI operation within the documented 2.30-3.46 V range; it is not the same rail as VCCPLL.

### B3 - Board is not routed

There are no track segments. No claims can yet be made about:

- TIA summing-node parasitics or the assumed 2.2 pF compensation;
- comparator-to-FPGA crosstalk;
- return-current continuity through actual routing/vias;
- boost hot-loop area and magnetic coupling;
- power-distribution impedance, cellular burst droop, or ground bounce;
- creepage/clearance after routing;
- thermal-pad via implementation;
- connector escape and mechanical accessibility.

### B4 - nRF9151 integration must replace generic carrier headers

The baseline is now direct integration of the nRF9151-LACA SiP. J7/J8 are generic headers and
must be replaced with the complete Nordic-reference RF/power/SIM/debug implementation. Supply
integrity, antenna matching and keep-out, physical SIM/eSIM protection, certification scope,
reset/debug access, and the approved reference BOM must be frozen before layout.

### B5 - No production RTL or nRF9151 firmware exists

The committed feature set is a specification only. The old FPGA RTL is unsafe as a starting implementation, and the RP2350 archive is a reference protocol prototype with acknowledged FIFO/drop and clustering concerns. A register map, clock-domain strategy, synchronizer policy, counter atomicity scheme, SPI protocol, reset behavior, overflow behavior, and verification suite are still required.

## High-priority electrical issues

### Power architecture

- AMS1117-3.3 cannot regulate from a LiPo/VSYS range stated as 3.5-5 V; its dropout eliminates regulation through much of a single-cell discharge. A solar/LiPo product needs a defined charger/protection/power-path design and probably buck-boost or a carefully budgeted low-dropout path.
- The nRF9151 requires at least 3.0 V for RF performance and 3.2 V is recommended. LTE current pulses must be supported locally without disturbing the TIA/DAC/FPGA rails.
- Input protection is absent: no fuse/current limiter, reverse-polarity protection, surge/ESD clamp, UVLO strategy, or connector standard is defined.
- The XC6206 1.2 V regulator lacks a shown input capacitor and needs a verified stability/output-capacitor implementation and transient budget for FPGA configuration/current steps.
- iCE40 decoupling is effectively absent. Add per-pin/bank capacitors, bulk capacitance, VCCPLL filtering, and configuration power-sequencing review.
- Analog and digital 3.3 V share a plane. A single ground is correct, but separate filtered/regulator branches for sensitive analog power and noisy RF/digital power should be considered without splitting ground.

### HV generation and safety

- TPS61170 is limited to 38 V output and is only suitable for the low-voltage SiPM option. It cannot be a BOM variant for the roughly 58 V Hamamatsu implementation without a different topology.
- With R11/R12/R13 present, the actual ideal setpoint is approximately `37.7 V - 2.7*HV_TRIM`, not the annotated 34.4 V divider result. Startup DAC state and failure behavior must be explicitly analyzed.
- `EN_HV` benefits from the TPS61170 internal pulldown, but the complete safe-start sequence still needs definition: MCU absent, FPGA unconfigured, DAC reset/midscale, cable disconnected, ADC fault, and firmware crash.
- HV_MON is suitable near 32 V but rises above 3.3 V near the Hamamatsu bias. Divider, ADC input network, settling, leakage error, clamp current, and fault overvoltage must be redesigned per selected carrier ADC.
- 0402 100 kOhm channel resistors and the 0402 1 MOhm divider resistor need verified continuous working-voltage and pulse ratings. Larger packages or series stacks are preferable at 30-60 V.
- 50 V capacitors have inadequate margin for a 58 V build. The proposed 2.2 uF/50 V C0G-or-film part in a 1206 footprint is not a realistic generic placeholder; an actual stocked component and its bias/temperature behavior must be selected.
- A touchable U.FL shield carrying 30-58 V creates hot-plug, contamination, ESD, service, and user-contact concerns. It may remain a deliberate architecture, but needs a connector rating review, discharge time, current limiting, labels/keying, and a field-service procedure.

### Analog front end

- The OPA858 model is a parameterized behavioral approximation, not the TI transistor-level/encrypted model. It is useful for topology intuition, but its numerical 0 dB peaking, overload recovery, noise, and ToT claims should be treated as preliminary.
- The quoted noise calculation uses a flat broadband noise-density approximation and omits 1/f noise, DAC/reference noise, supply noise, comparator kickback, PCB leakage/parasitics, SiPM excess noise/crosstalk/afterpulsing, and ambient-light current.
- One 100 nF + 1 uF pair is described as serving both the OPA858 and comparator. At multi-GHz GBW, each IC needs its own datasheet-compliant local decoupling and extremely short return path. TI's current OPA858 examples use 0.1 uF plus 6.8 uF supply bypassing.
- The BAV99 rail clamps can inject SiPM/HV transient charge into 3.3 V and back-power an unpowered board. Model power sequencing and use a defined low-capacitance protection strategy.
- The common VBOT saves DAC channels but makes a shared-noise/shared-fault node. Preserve individual RC isolation, add test access, and decide whether per-channel baseline trim is needed for offset/calibration yield.
- A 3 p.e. threshold is a sensible starting hypothesis, not yet a field-validated optimum. It must be established from measured dark-rate and muon-efficiency curves across temperature, device spread, optical yield, and ambient leakage.

### Digital, timing, and calibration

- Async comparator inputs require an explicit capture architecture; ordinary two-flop synchronization can miss narrow pulses. Use asynchronous set/capture or oversampling designed and formally/simulation verified for minimum pulse width, metastability, and multi-channel skew.
- Exact-subset semantics need a precise event-clustering definition when pulses overlap only partially or straddle windows. Define leading-edge vs interval overlap semantics, tie-breaking, holdoff, retrigger, and counter saturation.
- ToT with 10 ns bins is useful for discrimination/gain tracking but is not a muon energy spectrometer. Validate its stability against threshold drift, saturation, afterpulsing, fiber position, and temperature.
- The charge-injection network is not implemented. It is essential for a remote fleet and should be added per channel with controlled amplitude, low parasitic capacitance, isolation, and a calibration traceability plan.
- Only two NTC inputs are implemented for four SiPM channels. Either add four channels or explicitly choose paired/shared sensing based on measured thermal gradients.
- The three LED paths have no LEDs; the current schematic connects 3.3 V through 100 Ohm directly to FPGA RGB pins. Either add actual LEDs with a verified current scheme or mark the resistors DNP/remove them.
- Spare FPGA pins are marked no-connect in the schematic, so the promise to route them to test pads cannot be fulfilled without changing the schematic.
- Add SWD/JTAG/debug access for the nRF carrier, FPGA programming/recovery access, SPI/I2C/UART test pads, rail/HV test points, and a factory test fixture plan.

## Mechanical, optical, and scientific viability

- The legacy hardware proves that the panel/fiber/SiPM concept is physically buildable, but the documentation disagrees on light yield. The website/manual says roughly 30-50 photons per event, while the electronics redesign assumes roughly 30 detected photoelectrons and a 20-100 p.e. range. This must be resolved with measured single-p.e.-calibrated distributions on representative finished panels.
- The public site describes both 145 mm legacy panels and later 200 mm designs. Geometry, layer spacing, number of paddles, overlap, orientation, and acceptance are not frozen.
- gLOWCOST's network objectives require pressure correction, temperature stability, absolute/relative detector calibration, station metadata, timing quality flags, livetime, remote health diagnostics, secure updates, and reproducible manufacturing.
- A BME280 inside an enclosure may measure PCB self-heating rather than ambient air. Its placement, vent/membrane, solar shielding, and response time need an environmental design.
- For global outdoor deployment, define enclosure IP rating, condensation strategy, operating temperature, UV exposure, cable strain relief, lightning/ESD environment, antenna radome/ground plane, and service lifetime.
- GNSS PPS is useful for inter-station shower work. Atmospheric muon-rate monitoring itself usually needs stable rates and environmental corrections more than 10 ns timestamps. The scientific priorities should determine whether always-on GNSS power is justified.

## Software and fleet issues

- The 2016-2019 Node/WiringPi/Bower/MySQL stack is historical only. It has obsolete dependencies, example credentials, weak input/query handling, and no modern security/update model.
- The next generation needs authenticated telemetry, encrypted OTA update with rollback, per-device identity, monotonic schema/versioning, local buffering through outages, deduplication, clock-quality flags, configuration audit history, and remote safe-mode/recovery.
- LTE-M/NB-IoT availability, roaming, SIM/eSIM lifecycle, data plan, APN provisioning, and fallback behavior must be validated for every deployment region.
- Define raw-vs-aggregated data retention. For scientific reproducibility, reports should include firmware/RTL versions, configuration hash, thresholds, HV, temperature, pressure, livetime, deadtime, overflow/drop counters, PPS quality, reset reason, and calibration state.

## Prioritized redesign questions

### Must answer before schematic redesign

1. Which SiPM is the production baseline: MicroFC-30035 or S13360-2050VE? What measured p.e. distribution and dark-rate curve exists for the finished panel at the intended overvoltage and temperature range?
2. What is the frozen detector geometry: tile size/thickness, number of paddles, layer spacing, fiber topology, channel mapping, and desired angular acceptance?
3. Is the primary measurement long-term atmospheric/space-weather rate, educational counting, local muon lifetime, or inter-station air-shower coincidence? Rank these; they imply different timing, calibration, power, and data needs.
4. What is the average and worst-case power budget in watts, required autonomy, panel/battery size, minimum winter irradiance, and operating temperature?
5. Which exact nRF9151 carrier/module will be used, with pin map, dimensions, antenna, certifications, SIM/eSIM, supply requirements, and peak-current profile?
6. Can the analog rail become a clean 5 V rail so the OPA858 can operate at VBOT=2.4 V, or must the entire front end remain on 3.3 V?
7. Is HV on the exposed U.FL shield an immutable requirement? If yes, what connector voltage rating, touch/hot-plug policy, discharge time, and field-service constraints are acceptable?
8. Will the PCB include the solar charger, battery protection, fuel gauge, and power-path converter, or interface to a separately qualified power module?

### Must answer before layout freeze

9. What enclosure, mounting-hole, connector-edge, antenna keep-out, cable direction, and PCB size constraints are fixed?
10. Are all four per-SiPM NTCs required? Where are the sensors physically located and how are their two-wire connections carried alongside the SiPM coax?
11. What minimum/maximum comparator pulse widths and event rates have been measured, including afterpulses and large saturation events?
12. What coincidence semantics are scientifically required for overlapping pulses, and what window/holdoff ranges must be supported?
13. Is dual-threshold ToT worth the extra four comparators, or should the spare DAC channels be reserved for per-channel baseline/trim and calibration?
14. What factory/field calibration hardware is required: electrical injection, optical LED injection, threshold scans, per-channel HV readback, and temperature chamber characterization?
15. What failure state is required for loss of MCU, DAC, ADC, FPGA configuration, GNSS, or network? In every case, should HV default off?
16. What fabrication/assembly target is binding: JLCPCB standard assembly only, hand-fitted SiPM/HV parts, four-layer impedance stack, conformal coating, and expected annual volume?

### Must answer before fleet deployment

17. Which countries/operators must be supported, and is LTE-M, NB-IoT, NTN, Wi-Fi, Ethernet, or local storage the required fallback?
18. What timestamp accuracy is scientifically necessary, and what is the permitted GNSS duty cycle/holdover error?
19. What calibration transfer standard makes counts comparable between stations and across replacement panels/SiPMs?
20. What data schema, reporting cadence, local retention, OTA security, device identity, and backend ownership model will replace the legacy stack?
21. What environmental qualification is required: temperature/humidity cycling, condensation, ESD, EFT/surge, radiated immunity/emissions, ingress protection, UV, vibration, and burn-in?
22. What are the quantitative acceptance criteria for muon efficiency, accidental rate, channel crosstalk, gain drift, timing skew, power, and uptime?

## Recommended next work order

1. Freeze science requirements, detector geometry, SiPM, carrier, and power architecture.
2. Correct OPA858 supply/baseline and iCE40 VCCPLL immediately; replace all provisional power/HV components with verified parts.
3. Build a one-channel analog test coupon with the actual SiPM/cable, selectable Cf, charge injection, comparator, and production stackup. Measure gain, stability, dark-rate threshold curve, crosstalk, ToT, overload recovery, temperature drift, and boost/RF susceptibility.
4. Write the FPGA/nRF interface specification and build verified RTL with a synthetic-pulse testbench before relying on a PCB.
5. Complete safe power/HV sequencing, carrier integration, four NTCs, calibration injection, test/debug access, and telemetry.
6. Route the board in the documented order, then run KiCad 10 ERC/DRC, netlist assertions, impedance/return-path inspection, power-integrity review, and independent schematic/layout peer review.
7. Produce prototype and EVT/DVT plans with explicit pass/fail criteria before committing to a fleet build.

## Key external specifications checked

- TI OPA858 current data sheet: https://www.ti.com/lit/ds/symlink/opa858.pdf
- TI TLV3601 data sheet: https://www.ti.com/lit/ds/symlink/tlv3601.pdf
- TI TPS61170 data sheet: https://www.ti.com/lit/ds/symlink/tps61170.pdf
- Lattice iCE40 UltraPlus data sheet: https://www.latticesemi.com/-/media/LatticeSemi/Documents/DataSheets/iCE/FPGA-DS-02008-1-9-iCE40-UltraPlus-Family-Data-Sheet.ashx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
- Nordic nRF9151 product page/specification: https://www.nordicsemi.com/Products/nRF9151
- Quectel LC76G hardware design: https://www.quectel.com/content/uploads/2023/05/Quectel_LC76G_Series_Hardware_Design_V1.3.pdf
- gLOWCOST project: https://cosmic.gsu.edu/glowcost/
- Muon Telescope project: https://muontelescope.com/

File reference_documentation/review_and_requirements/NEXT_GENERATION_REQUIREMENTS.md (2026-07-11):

# Next-Generation Muon Telescope Requirements

Status: baseline requirements captured 2026-07-11. Items marked PROVISIONAL require prototype
measurement or a component selection review.

## Scientific priorities

In priority order:

1. Inter-station extensive-air-shower coincidence.
2. Long-duration atmospheric and space-weather muon-rate monitoring.
3. Directional tracking.

The instrument must preserve raw timing-quality and livetime metadata while also producing
stable, environmentally corrected rate products.

## Detector geometry

- Baseline panel: 200 x 200 x 10 mm plastic scintillator.
- One glued, embedded wavelength-shifting fiber routed in a loop.
- Baseline telescope: at least three panel layers; final layer spacing and mechanical orientation
  remain configurable because they set solid-angle acceptance and tracking resolution.
- Four analog channels on the controller. Other panel geometries must remain possible.
- Production SiPM: onsemi MicroFC-30035.
- Existing GSU/sPHENIX-derived measured panel data must be imported and analyzed in calibrated
  photoelectrons before analog dynamic range is frozen.

## Analog acquisition

- Four DC-coupled SiPM TIA channels, subject to correcting the OPA858 common-mode violation.
- Preferred fix: clean 5 V analog rail for OPA858 and a separately filtered reference/DAC domain;
  validate with an official model and one-channel coupon.
- Two comparator thresholds per channel for dual-threshold ToT: eight thresholds total.
- Independent per-channel baseline trim: four outputs.
- One HV trim output plus at least three spare analog outputs.
- Preferred DAC provision: two 8-channel DACs (16 outputs total), with readback or factory
  calibration of every output. DAC80508-class SPI devices are a candidate; final choice must be
  validated for output range, reference noise, startup state, availability, and power.
- Nominal 3 p.e. trigger remains PROVISIONAL. Hardware must support calibrated scans from below
  1 p.e. through the full muon-efficiency plateau.
- Per-channel charge injection and optical test injection are required.

## SiPM interconnect

- HV on a touchable U.FL shield is no longer required and should be removed.
- Preferred signal connector: coax center = SiPM anode signal, shield = ground.
- Provide a keyed, touch-safe auxiliary connector per channel for SiPM bias, cold-side NTC,
  TEC power, and optional hot-side NTC/fan signals. A combined locking hybrid connector may be
  evaluated if signal integrity and service safety remain adequate.
- Default HV state must be off under loss of MCU, DAC, firmware, cable, or sensor validity.

## Timing and digital processing

- iCE40UP5K remains the timing device, with VCCPLL corrected to filtered 1.2 V.
- External TCXO and GNSS PPS remain required.
- PROVISIONAL timing targets:
  - FPGA system clock: 100 MHz or faster, giving 10 ns base bins.
  - Capture any active-low pulse >= 5 ns without loss.
  - Programmable coincidence window: 10 ns to 2 us.
  - Programmable/bypassable holdoff: 0 to at least 50 us.
  - Inter-channel timestamp skew after calibration: <= 2 ns typical, <= 5 ns over temperature.
  - PPS timestamp uncertainty reported per station; target <= 50 ns when locked.
- Required FPGA products: raw singles, exact-subset counts, leading/trailing timestamps,
  dual-threshold ToT histograms, shadow-window accidentals, muon-lifetime histogram,
  livetime/deadtime, overflow/drop counters, PPS counter latch, and calibration-pulse control.
- Production RTL requires CDC/metastability analysis, synthetic-pulse verification, formal or
  exhaustive counter/register tests, and atomic SPI snapshots.

## Cellular controller

- Controller: integrate the nRF9151-LACA SiP directly, following Nordic's reference layout,
  RF grounding, antenna matching, SIM protection, approved BOM, and certification guidance.
  The prior generic J7/J8 carrier headers are dropped from the baseline.
- Initial regions: European Union and United States.
- Connectivity: Onomondo or Deutsche Telekom nuSIM/eSIM plus a physical SIM option.
- Radio support: LTE-M and NB-IoT; roaming, APN provisioning, PSM/eDRX, physical-SIM ESD, and
  antenna tuning must be validated in both regions.
- Required security: unique device identity, encrypted authenticated telemetry, signed OTA with
  rollback, configuration audit log, secure recovery, and credential provisioning.

## USB-C power and power delivery

- The instrument must operate from USB-C.
- Implement a standards-compliant USB-C PD sink; do not rely on passive CC resistors for the TEC
  power case.
- Recommended input profiles: 5 V fallback for detector operation without active cooling, and
  15 V/3 A or 20 V/5 A negotiated modes for TEC operation.
- Preferred PD starting point: TPS25751-class 100 W sink/controller. If a 2-4 cell battery is
  integrated, evaluate the documented TPS25751 + BQ25798 pairing; use the corresponding TI
  reference design rather than creating the PD/power-path implementation from first principles.
- Provide input ESD/surge protection, eFuse/current limiting, reverse-current protection, UVLO,
  telemetry, and controlled rail sequencing.
- Generate at least: RF/controller supply, quiet 5 V analog, 3.3 V digital, filtered 3.3 V
  comparator/reference as needed, 1.2 V FPGA core/PLL, approximately 30 V SiPM bias, and TEC rail.
- Maintain one ground system, but isolate noisy converters through placement, filtered branches,
  current-return control, and acquisition-aware switching.
- Battery/solar support is desired on-board or through a qualified module: charger, protection,
  power path, fuel gauge, external MPPT/solar interface, and safe USB/battery arbitration.

## Four-channel Peltier/TEC subsystem

- One independently controlled TEC output per SiPM channel.
- Cooling goal is reduced dark count and stable gain, not unrestricted minimum temperature.
- Normal control modes:
  1. fixed SiPM temperature;
  2. fixed delta below ambient; and
  3. dew-point-limited mode, maintaining the cold assembly at least 3 degC above calculated dew
     point unless the SiPM cavity is sealed and dry.
- Sensors per channel:
  - mandatory cold-side 10 kOhm NTC adjacent to SiPM;
  - strongly recommended hot-side/heatsink NTC;
  - enclosure ambient temperature/humidity/pressure sensor in ventilated, solar-shielded airflow.
- Add a multi-channel external ADC because HV_MON plus 4-8 thermal sensors exceed the practical
  nRF9151 ADC allocation and remote accuracy needs.
- TEC driver requirements per channel (PROVISIONAL until TEC selected):
  - 0-3 A bidirectional current control;
  - preferred driver candidate: MAX1968, which is an active-production, EMI-optimized bipolar
    +/-3 A TEC controller from a 3.0-5.5 V rail; create a dedicated high-current 5 V TEC rail from
    the negotiated PD input;
  - current and voltage telemetry;
  - hardware current limit, open/short detection, thermal shutdown, and default off;
  - filtered/synchronized PWM or linear current regulation so switching does not create triggers.
- Put TEC power stages and inductors in a quarantined region or on a separate daughterboard.
- Hard interlocks: disable TEC on invalid NTC, hot-side overtemperature, absent fan, excessive
  condensation risk, overcurrent, or insufficient PD contract.
- Mechanical design must include cold-side insulation, low-conductivity mounting, a real hot-side
  heat path, fan/heatsink monitoring, drainage/condensation management, and service access.

## Environmental and scientific telemetry

Every report must contain:

- station ID, firmware/RTL/configuration versions and reset reason;
- UTC/PPS lock, counter-per-PPS, timing uncertainty, and holdover state;
- singles, exact subsets, dual-ToT histograms, accidentals, livetime/deadtime, and overflow/drop;
- thresholds, baselines, HV setpoint/readback, SiPM temperatures, TEC currents/power, hot-side
  temperatures, ambient temperature/humidity/pressure, supply rails, and PD contract;
- pressure-corrected and uncorrected counts, with correction coefficients/version retained;
- calibration state and last electrical/optical self-test result.

## Initial engineering acceptance targets

These are reasonable prototype targets and must be tightened from measured data:

- Per-panel muon detection efficiency: >= 95% at the selected operating point.
- Electronics-only false-trigger rate: < 0.01 Hz/channel.
- Measured accidental coincidence contribution: < 1% of accepted coincidence rate, continuously
  estimated by shadow windows.
- Electrical channel-to-channel false coincidence during injection: < 1e-4 per injected pulse.
- Gain/threshold-equivalent drift after compensation: <= 2% over the qualified temperature range.
- No event loss at 10x the highest measured dark/signal rate; all overflow is counted and reported.
- Station livetime: >= 99.5% excluding declared updates/calibration; RF/TEC blanking reported.
- TEC regulation: +/-0.25 degC steady state; hot-side and dew-point interlocks independently tested.
- USB-C 5 V fallback must retain safe counting and telemetry with TECs disabled.

## Open measurements and selections

1. Import the user's measured single-p.e./muon distributions and temperature scans.
2. Select exact MicroFC-30035 variant/package, overvoltage, TEC, cold plate, heatsink, and fan.
3. Freeze number of panels and layer spacing for the baseline station.
4. Freeze the nRF9151-LACA reference-layout implementation and antenna system.
5. Select the USB-C PD controller, battery/solar power-path architecture, TEC driver, external
   ADC, DACs, and all regulator parts.
6. Decide whether the TEC subsystem resides on the detector PCB or a replaceable power daughterboard.

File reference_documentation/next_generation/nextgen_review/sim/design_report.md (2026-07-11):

# 4-Channel SiPM Muon Telescope — TIA Front-End Design & Simulation Report

Revision: 2026-06-10 · Topology: DC-coupled anode-readout TIA (OPA858) + fast comparator (TLV3601) · Verified in ngspice-42

---

## 1. Architecture summary

Each of the four channels is:

```
HV_QUIET ──R1 100k──┬── CATH (local 100n C0G reservoir, C1)
                    │
                 SiPM D1 (S13360-2050VE, K up / A down)
                    │ anode
                    R2 10Ω ── INA (summing node, BAV99 clamps to 3V3/GND)
                    │
              ┌─────┴──── −IN  U1 OPA858 ────┬── TIA_OUT
              │  Rf 2k ‖ Cf 2.2p feedback    │
   CHx_VBOT ──┴── +IN (2.40 V, DAC4–7)       │
                                             ├── +IN  U2 TLV3601 ── R5 33Ω ── CHx_CMP → iCE40
                              CHx_THRESH ────┴── −IN (2.326 V, DAC0–3)
```

The decisive topology choice is **DC coupling of the SiPM anode to the TIA summing node**. Because the TIA holds its input at the VBOT potential (a virtual ground), the SiPM anode can sit there directly while the cathode carries the full bias. This **eliminates the input AC-coupling capacitor entirely**, and with it the baseline-undershoot and rate-dependent-threshold problems that an AC-coupled chain suffers. The SiPM dark current (sub-µA typical) flows through Rf and produces only a ~mV static offset. The effective overvoltage is V(CATH) − V(VBOT) = 32.4 − 2.4 = 30.0 V above... (set HV so that CATH − VBOT = Vbr + 3 V; with Vbr ≈ 53 V the real setpoint is HV_QUIET ≈ 58.4 V — the 32.4 V used in simulation is a placeholder that does not affect signal behavior, since only the pulse charge matters. **If the onsemi MicroFC-30035 is adopted, HV_QUIET ≈ 27.4 + 2.4 ≈ 29.8 V and the TPS61170 single-inductor boost shown in `hv_bias.svg` applies directly. For the Hamamatsu part, substitute a higher-ratio boost or the original MAX1932 — the filter chain and trim/readback structure are identical.**)

Pulse polarity: avalanche current is injected *into* the summing node, so TIA_OUT swings **down** from the 2.40 V baseline. The comparator takes TIA_OUT on IN+ and the threshold on IN−, producing the **active-low, idle-high** pulse the existing firmware/PIO convention and the planned iCE40 capture logic expect.

## 2. Design values and the reasoning behind them

**Rf = 2 kΩ, 1 %.** Sets transimpedance. Simulated conversion gain is **24.4 mV per photoelectron** (see §3) — 1 % resistors match the four channels to 1 %, so one DAC threshold table serves all channels.

**Cf = 2.2 pF, C0G.** From Cf = √(Cin/(π·Rf·GBW)) with Cin ≈ 143 pF (140 pF SiPM + clamps/protection ≈ 3 pF) and GBW = 5.5 GHz: 2.08 pF → 2.2 pF standard value. The AC sweep confirms this is the Butterworth point: **0.0 dB peaking, f₋₃dB = 52.5 MHz**. Cf = 1.0 pF peaks 3.6 dB (rings in transient); 4.7 pF is overdamped at 19 MHz. The OPA858 is decompensated (min gain 7), which is safe here because the high-frequency noise gain is 1 + Cin/Cf ≈ 66.

**OPA858 on a single 3.3 V rail.** VBOT = 2.40 V baseline leaves 2.25 V of downward swing to the lower output clamp — a linear range of **~92 p.e.** before clipping. FET input ⇒ negligible current noise into 2 kΩ. Iq ≈ 20 mA/channel; the accepted power cost. The drop-in lower-power alternative is characterized in §3.

**R2 = 10 Ω + BAV99 clamps.** Protects the input during HV power-up/fault transients (the SiPM terminal capacitance dumps charge when bias steps). 10 Ω adds negligible noise and, with the clamp capacitance, is included in the simulated Cin.

**TLV3601.** 2.5 ns tpd, ~1 mA, push-pull, ~6 mV internal hysteresis (modeled). With the smallest operating threshold at 1 p.e. = 24 mV, the hysteresis never causes chatter; overdrive at a 3 p.e. threshold is many times the hysteresis. R5 = 33 Ω damps the line into the iCE40 pin.

**Thresholds.** DAC7578 from the 3.3 V rail: LSB = 0.806 mV = **0.033 p.e.** — far finer than needed. Nominal operating point CHx_THRESH = 2.326 V = 3.0 p.e. below baseline. The threshold-scan calibration mode sweeps this code; the single-p.e. staircase appears at codes within ~30 LSB of baseline.
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

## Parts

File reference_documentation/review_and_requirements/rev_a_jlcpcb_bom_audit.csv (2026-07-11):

Quantity | References | Value_or_MPN | Package | JLCPCB_Part | Stock_Class | Decision
4 | R106 R116 R126 R136 | 2k 1% | 0402 | C4109 | Basic in stock | Keep
5 | R13 R101 R111 R121 R131 | 100k 1% | 0402 | C25741 | Basic in stock | Keep
4 | R102 R112 R122 R132 | 10R 1% | 0402 | C25077 | Basic in stock | Keep
9 | R10 R103 R104 R113 R114 R123 R124 R133 R134 | 1k 1% | 0402 | C11702 | Basic in stock | Keep
4 | R105 R115 R125 R135 | 33R 1% | 0402 | C25105 | Basic | Keep
1 | R11 | 270k 1% | 0603 | C22965 | Basic | Verify live stock
3 | R12 R32 R33 | 10k 1% | 0402 | C25744 | Basic | Keep
1 | R15 | 62k 1% | 0603 | C23221 | Basic | Keep
1 | R14 | 1M 1% | 0402 | C26083 | Basic | Verify working voltage
3 | R16 R30 R31 | 4.7k 1% | 0402 | C25900 | Basic | Keep
3 | R35 R36 R37 | 100R 1% | 0402 | C25076 | Basic | Remove or add LEDs
1 | R20 | 0R link | 0402 | TBD | Unresolved | Assign real 0R part
4 | C106 C116 C126 C136 | 2.2pF C0G | 0402 | C1559 | Catalogued | Re-simulate TIA
16 | C30 C31 C32 C33 C102 C103 C104 C112 C113 C114 C122 C123 C124 C132 C133 C134 | 100nF | 0402 | C1525 | Basic | Keep
1 | C13 | 10nF | 0402 | C15195 | Basic | Keep
5 | C22 C105 C115 C125 C135 | 1uF 25V X5R | 0402 | C52923 | Basic in stock | Keep
2 | C20 C21 | 10uF | 0603 | C19702 | Catalogued | Verify voltage and stock
4 | C101 C111 C121 C131 | 100nF 50V | 0805 | TBD | Unresolved | Select exact rated part
2 | C10 C11 | 1uF 50V | 1206 | TBD | Unresolved | Select exact rated part
1 | C12 | 2.2uF 50V | 1206 | TBD | Unresolved | Select using DC-bias curve
4 | D2 D3 D4 D5 | BAV99,215 | SOT-23 | C2500 | Basic in stock | Review input protection
1 | D10 | SS510B | SMB | C7420368 | Extended in stock | Keep
1 | L1 | SWPA4030S100MT | SMD 4x4mm | C38117 | Extended in stock | Correct footprint
1 | L2 | 100uH | 0805 | C68035 | Catalogued | Verify exact ratings and stock
4 | J2 J3 J4 J5 | BWU.FL-IPEX1 | SMD | C5137195 | Extended in stock | Redesign unsafe shell HV
3 | J1 J9 J10 | 1x2 2.54mm header | THT | TBD | Unresolved | Choose exact part
1 | J6 | 1x6 2.54mm header | THT | TBD | Unresolved | Replace placeholder
2 | J7 J8 | 1x10 2.54mm header | THT | TBD | Unresolved | Remove for direct nRF9151
4 | U101 U111 U121 U131 | OPA858IDSGR | WSON-8-EP 2x2 | C970232 | Extended supported | Correct ID and redesign bias
4 | U102 U112 U122 U132 | TLV3601IDBVR | SOT-23-5 | TBD | Stock unconfirmed | Pre-order/global-source or qualify alternate
1 | U10 | TPS61170DRVR | WSON-6 2x2 | C15163 | Extended in stock | Correct wrong C77205 note
1 | U11 | AMS1117-3.3 | SOT-223 | C6186 | Basic in stock | Replace with buck
1 | U12 | XC6206P122MR-G | SOT-23 | C424699 | Extended in stock | Verify 60mA limit
1 | U4 | DAC7578IPWR | TSSOP-16 | TBD | Stock unconfirmed | Redesign DAC architecture
1 | U5 | BME280 | LGA-8 | C92489 | Extended in stock | Keep
1 | U6 | W25Q128JVSIQ | SOIC-8 208mil | C97521 | Basic supported | Verify footprint and boot
1 | U3 | ICE40UP5K-SG48I | QFN-48-EP 7x7 | C2678152 | Extended in stock | Correct PLL rail
1 | X1 | 25MHz 3.3V oscillator | 2520-4 | TBD | Unresolved | Select exact stocked MPN

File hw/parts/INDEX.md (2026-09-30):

# Muon3 station — parts library

Generated by `bun tools/parts_index.ts`. Each `parts/<LCSC>/` folder holds `part.json` (footprint in mm + pin names, from LCSC/EasyEDA),
`datasheet.pdf`, `model.step` and `model.obj`. Passives share one footprint/3D model per package (the folder named in *Footprint from*).
TI parts also have `datasheet_full.pdf` where LCSC's copy is abridged.

| Refs | Value | MPN | Manufacturer | Package | LCSC | Footprint from | Datasheet | STEP |
|---|---|---|---|---|---|---|---|---|
| C2, C3, C10 | 10u | CL21A106KAYNNNE | SAMSUNG(三星) | C0805 | [C15850](https://jlcpcb.com/partdetail/C15850) |  | [pdf](C15850/datasheet.pdf) (7672 kB) | [step](C15850/model.step) |
| C4 | 22u | (generic) |  | C0805 | [C45783](https://jlcpcb.com/partdetail/C45783) | C15850 | [pdf](C15850/datasheet.pdf) (7672 kB) | [step](C15850/model.step) |
| C5, C9, C19, C21 | 1u | (generic) |  | C0402 | [C52923](https://jlcpcb.com/partdetail/C52923) | C1525 | [pdf](C1525/datasheet.pdf) (7672 kB) | [step](C1525/model.step) |
| C6, C8 | 10u | (generic) |  | C0603 | [C96446](https://jlcpcb.com/partdetail/C96446) | C14663 | [pdf](C14663/datasheet.pdf) (1105 kB) | [step](C14663/model.step) |
| C1, C7, C11, C16, C17, C18, C20, C23, C25, C27, C28, C30, C32, C34, C35, C37, C39, C41, C42, C44, C46, C48, C49, C51 | 100n | CL05B104KO5NNNC | SAMSUNG(三星) | C0402 | [C1525](https://jlcpcb.com/partdetail/C1525) |  | [pdf](C1525/datasheet.pdf) (7672 kB) | [step](C1525/model.step) |
| C12 | 1n | (generic) |  | C0402 | [C1523](https://jlcpcb.com/partdetail/C1523) | C1525 | [pdf](C1525/datasheet.pdf) (7672 kB) | [step](C1525/model.step) |
| C13, C15 | 1u | CL31B105KCHNNNE | SAMSUNG(三星) | C1206 | [C13832](https://jlcpcb.com/partdetail/C13832) |  | [pdf](C13832/datasheet.pdf) (7672 kB) | [step](C13832/model.step) |
| C14, C22, C29, C36, C43 | 100n | (generic) |  | C0805 | [C28233](https://jlcpcb.com/partdetail/C28233) | C15850 | [pdf](C15850/datasheet.pdf) (7672 kB) | [step](C15850/model.step) |
| C24, C31, C38, C45 | 2.7p | (generic) |  | C0402 | [C1561](https://jlcpcb.com/partdetail/C1561) | C1525 | [pdf](C1525/datasheet.pdf) (7672 kB) | [step](C1525/model.step) |
| C26, C33, C40, C47 | 1p | (generic) |  | C0402 | [C1550](https://jlcpcb.com/partdetail/C1550) | C1525 | [pdf](C1525/datasheet.pdf) (7672 kB) | [step](C1525/model.step) |
| D1 | STATUS | KT-0603R | KENTO | LED-SMD_L1.6-W0.8-R-RD | [C2286](https://jlcpcb.com/partdetail/C2286) |  | [pdf](C2286/datasheet.pdf) (597 kB) | [step](C2286/model.step) |
| D2, D3 | LL4148 | LL4148 | YONGYUTAI(永裕泰) | LL-34_L3.5-W1.5-LS3.5-FD | [C3015531](https://jlcpcb.com/partdetail/C3015531) |  | [pdf](C3015531/datasheet.pdf) (3926 kB) | [step](C3015531/model.step) |
| J1 | TYPE-C 16PIN 2MD(073) | TYPE-C 16PIN 2MD(073) | SHOU HAN(首韩) | USB-C-SMD_TYPE-C-16PIN-2MD-073 | [C2765186](https://jlcpcb.com/partdetail/C2765186) |  | [pdf](C2765186/datasheet.pdf) (1547 kB) | [step](C2765186/model.step) |
| J2, J3, J4, J5 | TILE 0 | U.FL-R-SMT-1(80) | HRS(广濑) | RF-SMD_FRF05002-JSS103M | [C88374](https://jlcpcb.com/partdetail/C88374) |  | [pdf](C88374/datasheet.pdf) (181 kB) | [step](C88374/model.step) |
| J6 | STEMMA QT | SM04B-SRSS-TB(LF)(SN) | JST | CONN-SMD_4P-P1.00_SM04B-SRSS-TB-LF-SN | [C160404](https://jlcpcb.com/partdetail/C160404) |  | [pdf](C160404/datasheet.pdf) (87 kB) | [step](C160404/model.step) |
| L1 | 150u | SMNR4018-151MT | SXN(顺翔诺) | IND-SMD_L4.0-W4.0_SMNR4018 | [C135260](https://jlcpcb.com/partdetail/C135260) |  | [pdf](C135260/datasheet.pdf) (2333 kB) | [step](C135260/model.step) |
| Q1 | BSS123LT1G | BSS123LT1G | onsemi(安森美) | SOT-23_L2.9-W1.3-P1.90-LS2.4-BR | [C78755](https://jlcpcb.com/partdetail/C78755) |  | [pdf](C78755/datasheet.pdf) (110 kB) | [step](C78755/model.step) |
| Q2 | 2N7002 | 2N7002 | CJ(江苏长电/长晶) | SOT-23-3_L2.9-W1.3-P1.90-LS2.4-BR | [C8545](https://jlcpcb.com/partdetail/C8545) |  | [pdf](C8545/datasheet.pdf) (537 kB) | [step](C8545/model.step) |
| R1, R2 | 5.1k | (generic) |  | R0402 | [C25905](https://jlcpcb.com/partdetail/C25905) | C25744 | [pdf](C25744/datasheet.pdf) (457 kB) | [step](C25744/model.step) |
| R3, R4, R18, R23 | 10k | 0402WGF1002TCE | UNI-ROYAL(厚声) | R0402 | [C25744](https://jlcpcb.com/partdetail/C25744) |  | [pdf](C25744/datasheet.pdf) (457 kB) | [step](C25744/model.step) |
| R5, R11, R16, R28, R33, R38, R43 | 1k | (generic) |  | R0402 | [C11702](https://jlcpcb.com/partdetail/C11702) | C25744 | [pdf](C25744/datasheet.pdf) (457 kB) | [step](C25744/model.step) |
| R6, R7, R8, R9 | 4.7k | (generic) |  | R0402 | [C25900](https://jlcpcb.com/partdetail/C25900) | C25744 | [pdf](C25744/datasheet.pdf) (457 kB) | [step](C25744/model.step) |
| R10 | 2.2 | (generic) |  | R0805 | [C17521](https://jlcpcb.com/partdetail/C17521) | C17414 | [pdf](C17414/datasheet.pdf) (457 kB) | [step](C17414/model.step) |
| R12 | 10k | 0805W8F1002T5E | UNI-ROYAL(厚声) | R0805 | [C17414](https://jlcpcb.com/partdetail/C17414) |  | [pdf](C17414/datasheet.pdf) (457 kB) | [step](C17414/model.step) |
| R13, R14 | 510k | (generic) |  | R0805 | [C17733](https://jlcpcb.com/partdetail/C17733) | C17414 | [pdf](C17414/datasheet.pdf) (457 kB) | [step](C17414/model.step) |
| R15 | 20k | (generic) |  | R0402 | [C25765](https://jlcpcb.com/partdetail/C25765) | C25744 | [pdf](C25744/datasheet.pdf) (457 kB) | [step](C25744/model.step) |
| R17 | 68k | (generic) |  | R0402 | [C36871](https://jlcpcb.com/partdetail/C36871) | C25744 | [pdf](C25744/datasheet.pdf) (457 kB) | [step](C25744/model.step) |
| R19 | 100k | (generic) |  | R0402 | [C25741](https://jlcpcb.com/partdetail/C25741) | C25744 | [pdf](C25744/datasheet.pdf) (457 kB) | [step](C25744/model.step) |
| R20, R21 | 1M | (generic) |  | R0805 | [C17514](https://jlcpcb.com/partdetail/C17514) | C17414 | [pdf](C17414/datasheet.pdf) (457 kB) | [step](C17414/model.step) |
| R22 | 75k | (generic) |  | R0402 | [C25798](https://jlcpcb.com/partdetail/C25798) | C25744 | [pdf](C25744/datasheet.pdf) (457 kB) | [step](C25744/model.step) |
| R24 | 1.1k | (generic) |  | R0402 | [C25860](https://jlcpcb.com/partdetail/C25860) | C25744 | [pdf](C25744/datasheet.pdf) (457 kB) | [step](C25744/model.step) |
| R25, R30, R35, R40 | 47k | (generic) |  | R0805 | [C17713](https://jlcpcb.com/partdetail/C17713) | C17414 | [pdf](C17414/datasheet.pdf) (457 kB) | [step](C17414/model.step) |
| R26, R31, R36, R41 | 33k | (generic) |  | R0402 | [C25779](https://jlcpcb.com/partdetail/C25779) | C25744 | [pdf](C25744/datasheet.pdf) (457 kB) | [step](C25744/model.step) |
| R27, R32, R37, R42 | 100 | (generic) |  | R0402 | [C25076](https://jlcpcb.com/partdetail/C25076) | C25744 | [pdf](C25744/datasheet.pdf) (457 kB) | [step](C25744/model.step) |
| R29, R34, R39, R44 | 33 | (generic) |  | R0402 | [C25105](https://jlcpcb.com/partdetail/C25105) | C25744 | [pdf](C25744/datasheet.pdf) (457 kB) | [step](C25744/model.step) |
| SW1 | BOOT | TS-1187A-B-A-B | XKB Connection(中国星坤) | SW-SMD_4P-L5.1-W5.1-P3.70-LS6.5-TL_H1.5 | [C318884](https://jlcpcb.com/partdetail/C318884) |  | [pdf](C318884/datasheet.pdf) (786 kB) | [step](C318884/model.step) |
| U1 | ESP32-S3-WROOM-1U-N16R8 | ESP32-S3-WROOM-1U-N16R8 | ESPRESSIF(乐鑫) | WIRELM-SMD_ESP32-S3-WROOM-1U | [C3013946](https://jlcpcb.com/partdetail/C3013946) |  | [pdf](C3013946/datasheet.pdf) (835 kB) | [step](C3013946/model.step) |
| U2 | BME280 | BME280 | Bosch(博世) | LGA-8_BME280_BL | [C92489](https://jlcpcb.com/partdetail/C92489) |  | [pdf](C92489/datasheet.pdf) (1478 kB) | [step](C92489/model.step) |
| U3 | USBLC6-2SC6 | USBLC6-2SC6 | UMW(友台半导体) | SOT-23-6_L2.9-W1.6-P0.95-LS2.8-BL | [C2687116](https://jlcpcb.com/partdetail/C2687116) |  | [pdf](C2687116/datasheet.pdf) (224 kB) | [step](C2687116/model.step) |
| U4 | AMS1117-3.3 | AMS1117-3.3 | Advanced Monolithic Systems | SOT-223-3_L6.5-W3.4-P2.30-LS7.0-BR | [C6186](https://jlcpcb.com/partdetail/C6186) |  | [pdf](C6186/datasheet.pdf) (93 kB) | [step](C6186/model.step) |
| U5 | TLV75733PDBVR | TLV75733PDBVR | TI(德州仪器) | SOT-23-5_L2.9-W1.6-P0.95-LS2.8-BL | [C485517](https://jlcpcb.com/partdetail/C485517) |  | [full](C485517/datasheet_full.pdf) | [step](C485517/model.step) |
| U6 | MC34063ADR | MC34063ADR | TI(德州仪器) | SOIC-8_L4.9-W3.9-P1.27-LS6.0-BL | [C100023](https://jlcpcb.com/partdetail/C100023) |  | [full](C100023/datasheet_full.pdf) | [step](C100023/model.step) |
| U7, U8 | MCP4728T-E/UN | MCP4728T-E/UN | MICROCHIP(美国微芯) | MSOP-10_L3.0-W3.0-P0.50-LS4.9-BL | [C478093](https://jlcpcb.com/partdetail/C478093) |  | [pdf](C478093/datasheet.pdf) (2937 kB) | [step](C478093/model.step) |
| U9, U11, U13, U15 | OPA356AIDBVR | OPA356AIDBVR | TI(德州仪器) | SOT-23-5_L3.0-W1.7-P0.95-LS2.8-BR | [C183100](https://jlcpcb.com/partdetail/C183100) |  | [pdf](C183100/datasheet.pdf) (817 kB) | [step](C183100/model.step) |
| U10, U12, U14, U16 | LMV7219M5/TR | LMV7219M5/TR | HGSEMI(华冠) | SOT-23-5_L3.0-W1.5-P0.95-LS2.8-BL | [C20613263](https://jlcpcb.com/partdetail/C20613263) |  | [full](C20613263/datasheet_full.pdf) | [step](C20613263/model.step) |
| U17 | SC7A20HTR | SC7A20HTR | SILAN(士兰微) | LGA-12_L2.0-W2.0-P0.50-TL | [C19274408](https://jlcpcb.com/partdetail/C19274408) |  | [pdf](C19274408/datasheet.pdf) (1437 kB) | [step](C19274408/model.step) |

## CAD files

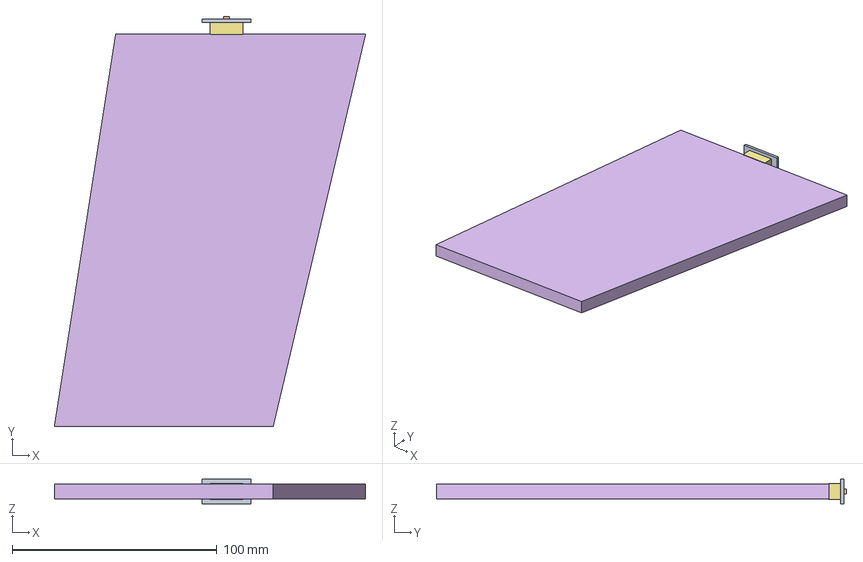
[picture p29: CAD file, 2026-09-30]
cad/sphenix_hcal/step/InnerHCalTile03_assembly.step
152.0 x 200.1 x 12.0 mm
Tile0_Body
Tile0_Fiber
Tile0_Coating
Tile0_WrapAl
Tile0_WrapCling
Tile0_WrapVinyl
Tile0_Coupler
Tile0_SiPM
Tile0_SiPM_PCB
Tile0_UFL

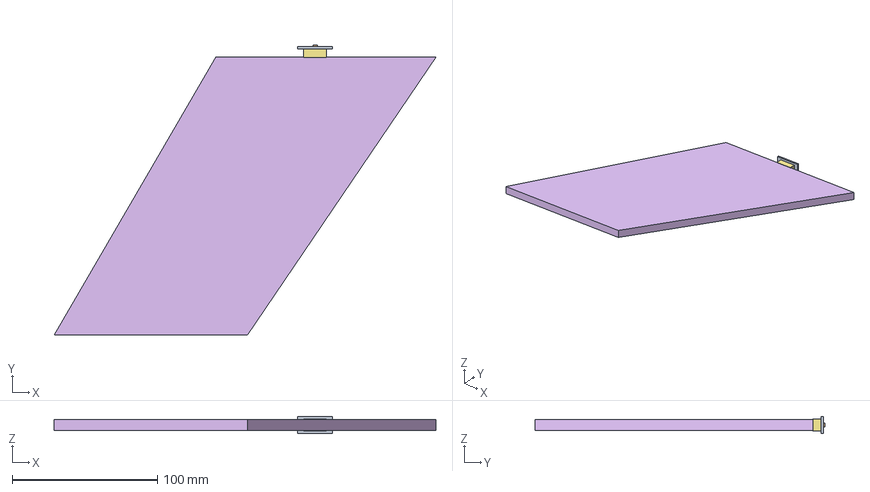
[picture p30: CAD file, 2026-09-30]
cad/sphenix_hcal/step/InnerHCalTile08_assembly.step
263.2 x 200.1 x 12.0 mm
Tile0_Body
Tile0_Fiber
Tile0_Coating
Tile0_WrapAl
Tile0_WrapCling
Tile0_WrapVinyl
Tile0_Coupler
Tile0_SiPM
Tile0_SiPM_PCB
Tile0_UFL

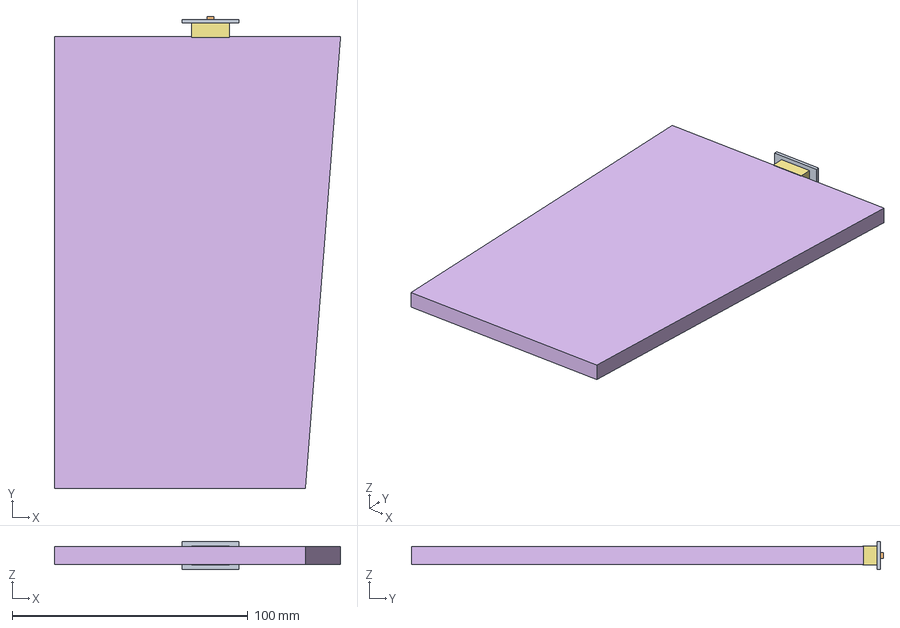
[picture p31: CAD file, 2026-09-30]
cad/sphenix_hcal/step/InnerHCalTile01_assembly.step
121.4 x 200.1 x 12.0 mm
Tile0_Body
Tile0_Fiber
Tile0_Coating
Tile0_WrapAl
Tile0_WrapCling
Tile0_WrapVinyl
Tile0_Coupler
Tile0_SiPM
Tile0_SiPM_PCB
Tile0_UFL

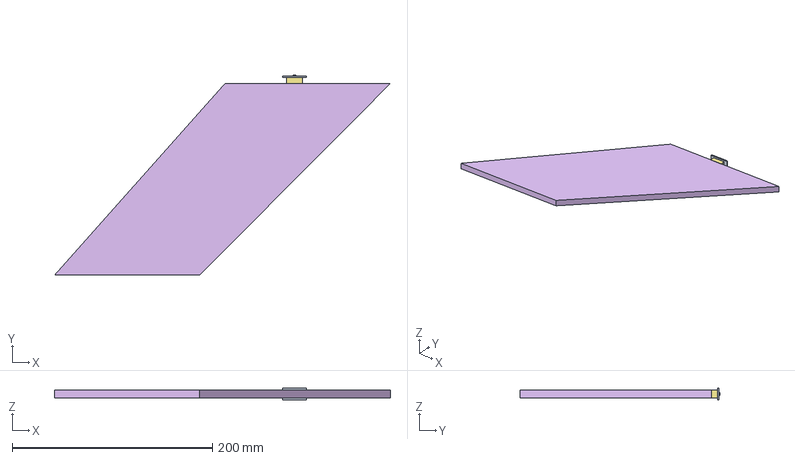
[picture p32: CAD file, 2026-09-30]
cad/sphenix_hcal/step/InnerHCalTile11_assembly.step
335.7 x 200.1 x 12.0 mm
Tile0_Body
Tile0_Fiber
Tile0_Coating
Tile0_WrapAl
Tile0_WrapCling
Tile0_WrapVinyl
Tile0_Coupler
Tile0_SiPM
Tile0_SiPM_PCB
Tile0_UFL

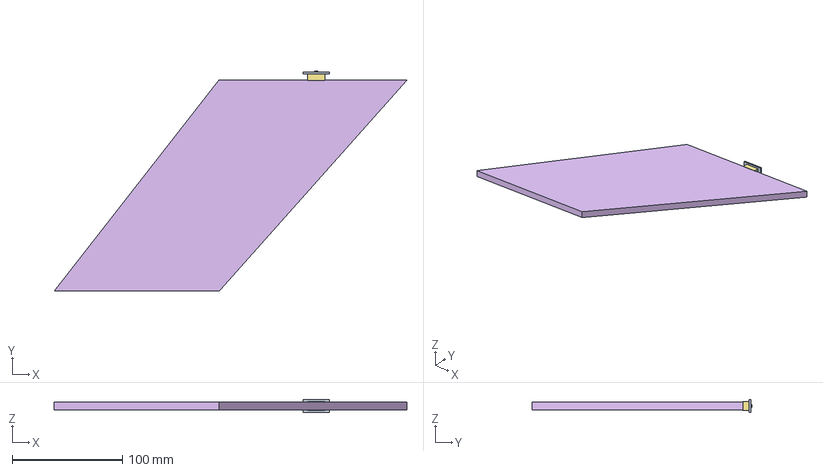
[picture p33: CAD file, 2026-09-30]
cad/sphenix_hcal/step/InnerHCalTile10_assembly.step
320.4 x 200.1 x 12.0 mm
Tile0_Body
Tile0_Fiber
Tile0_Coating
Tile0_WrapAl
Tile0_WrapCling
Tile0_WrapVinyl
Tile0_Coupler
Tile0_SiPM
Tile0_SiPM_PCB
Tile0_UFL

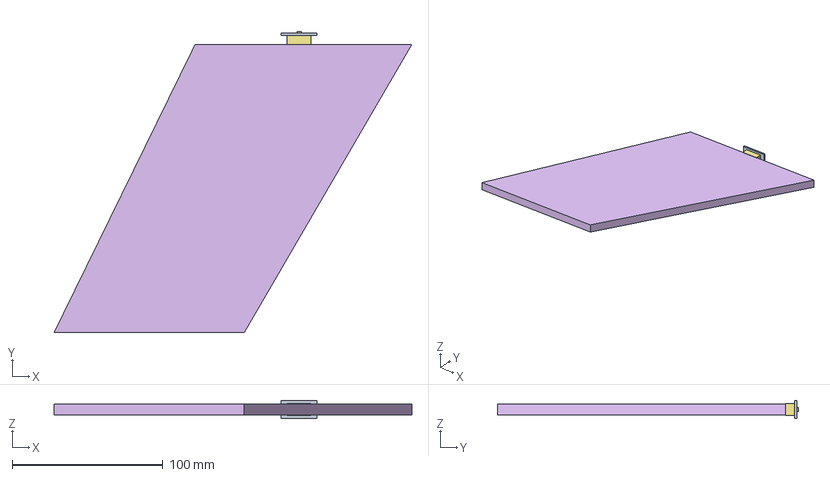
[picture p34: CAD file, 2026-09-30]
cad/sphenix_hcal/step/InnerHCalTile07_assembly.step
237.8 x 200.1 x 12.0 mm
Tile0_Body
Tile0_Fiber
Tile0_Coating
Tile0_WrapAl
Tile0_WrapCling
Tile0_WrapVinyl
Tile0_Coupler
Tile0_SiPM
Tile0_SiPM_PCB
Tile0_UFL

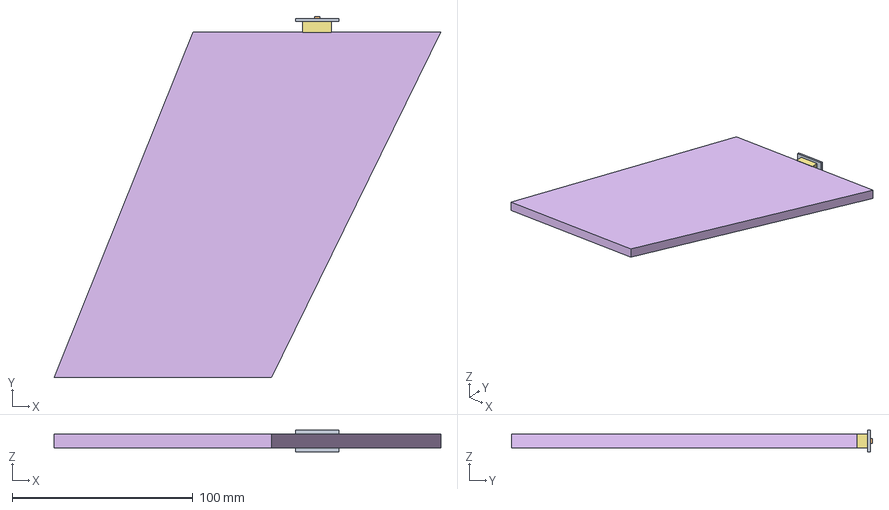
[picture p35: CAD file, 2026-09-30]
cad/sphenix_hcal/step/InnerHCalTile06_assembly.step
214.4 x 200.1 x 12.0 mm
Tile0_Body
Tile0_Fiber
Tile0_Coating
Tile0_WrapAl
Tile0_WrapCling
Tile0_WrapVinyl
Tile0_Coupler
Tile0_SiPM
Tile0_SiPM_PCB
Tile0_UFL

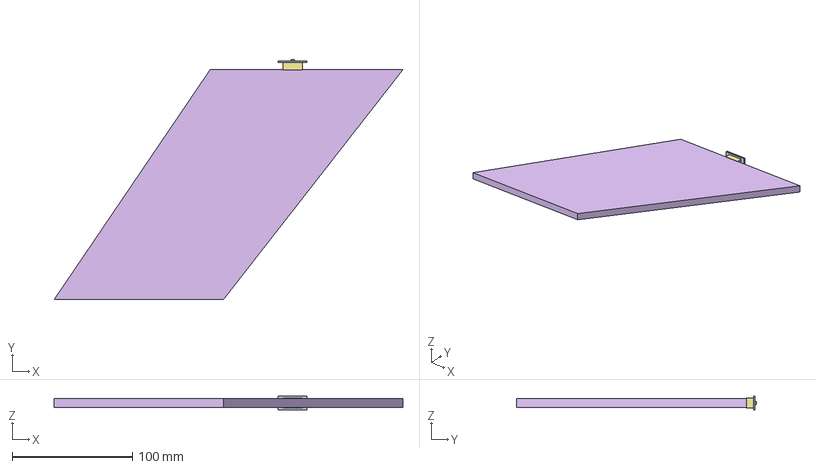
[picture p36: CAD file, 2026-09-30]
cad/sphenix_hcal/step/InnerHCalTile09_assembly.step
290.5 x 200.1 x 12.0 mm
Tile0_Body
Tile0_Fiber
Tile0_Coating
Tile0_WrapAl
Tile0_WrapCling
Tile0_WrapVinyl
Tile0_Coupler
Tile0_SiPM
Tile0_SiPM_PCB
Tile0_UFL

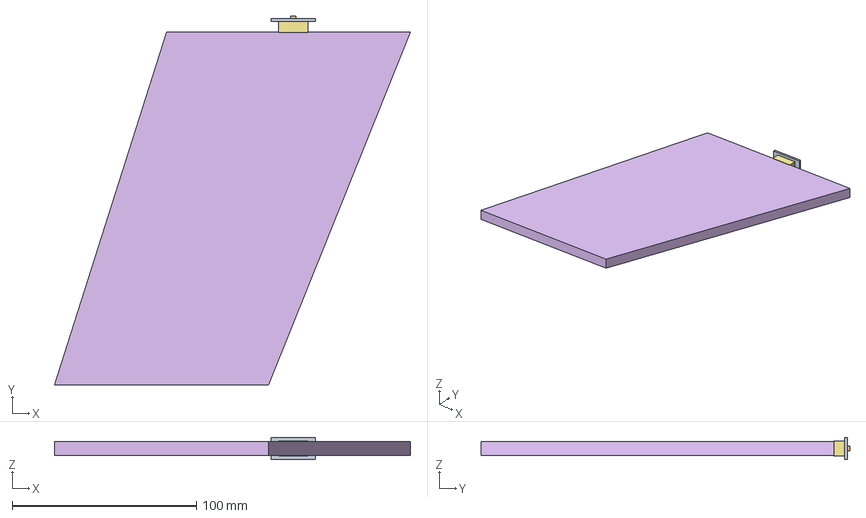
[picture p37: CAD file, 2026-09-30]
cad/sphenix_hcal/step/InnerHCalTile05_assembly.step
193.2 x 200.1 x 12.0 mm
Tile0_Body
Tile0_Fiber
Tile0_Coating
Tile0_WrapAl
Tile0_WrapCling
Tile0_WrapVinyl
Tile0_Coupler
Tile0_SiPM
Tile0_SiPM_PCB
Tile0_UFL

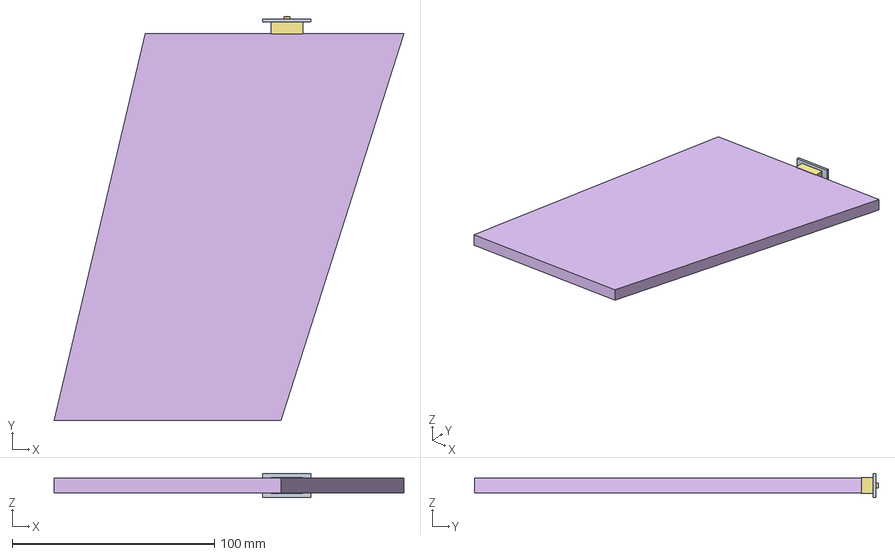
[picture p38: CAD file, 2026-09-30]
cad/sphenix_hcal/step/InnerHCalTile04_assembly.step
173.2 x 200.1 x 12.0 mm
Tile0_Body
Tile0_Fiber
Tile0_Coating
Tile0_WrapAl
Tile0_WrapCling
Tile0_WrapVinyl
Tile0_Coupler
Tile0_SiPM
Tile0_SiPM_PCB
Tile0_UFL

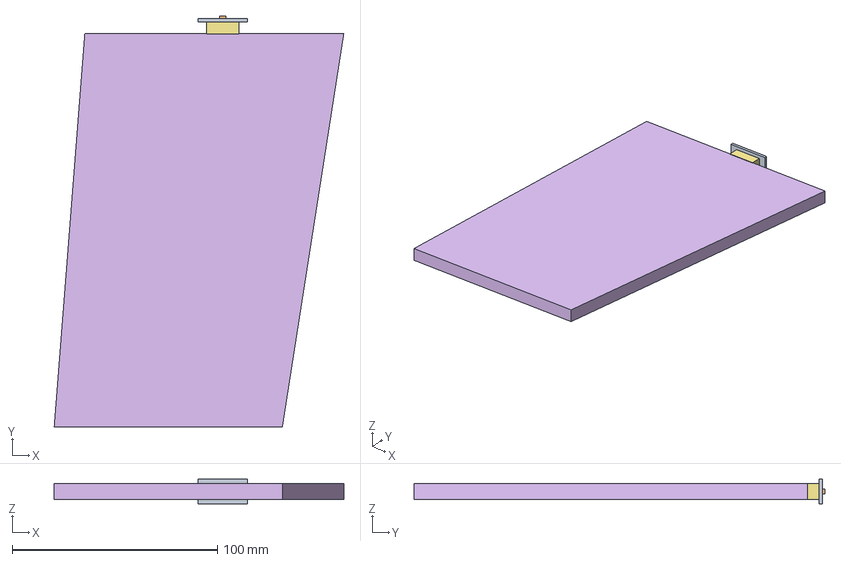
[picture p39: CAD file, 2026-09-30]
cad/sphenix_hcal/step/InnerHCalTile02_assembly.step
141.0 x 200.1 x 12.0 mm
Tile0_Body
Tile0_Fiber
Tile0_Coating
Tile0_WrapAl
Tile0_WrapCling
Tile0_WrapVinyl
Tile0_Coupler
Tile0_SiPM
Tile0_SiPM_PCB
Tile0_UFL

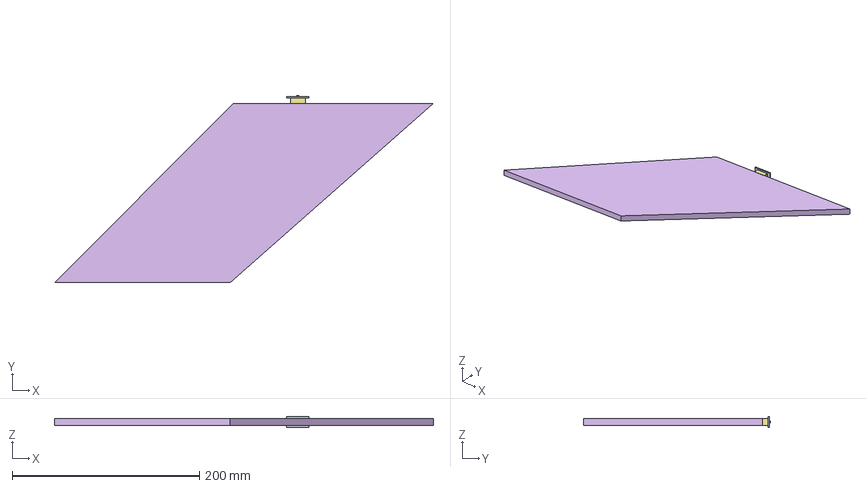
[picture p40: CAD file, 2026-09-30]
cad/sphenix_hcal/step/InnerHCalTile12_assembly.step
404.6 x 200.1 x 12.0 mm
Tile0_Body
Tile0_Fiber
Tile0_Coating
Tile0_WrapAl
Tile0_WrapCling
Tile0_WrapVinyl
Tile0_Coupler
Tile0_SiPM
Tile0_SiPM_PCB
Tile0_UFL

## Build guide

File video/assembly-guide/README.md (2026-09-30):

# Muon3

A 1920x1080 @ 30 fps video made with [fframes](https://github.com/dmtrKovalenko/fframes),
rendered with the Skia (Metal) backend.

| file | what |
| --- | --- |
| `src/lib.rs` | the video: scenes, animation, audio map |
| `src/main.rs` | the command line (`fframes::cli`) |
| `media/` | fonts, images and audio embedded into the binary |
| `tests/frames.rs` | frame snapshots and a check of every frame for problems |

## Work on it

```sh
cargo run --release -- timeline                      # scenes, duration, audio tracks
cargo run --release -- frame 1s,50%,end              # PNGs into frames/ and the problems found in them
cargo run --release -- strip DataScene -n 8        # contact sheet, writes strip.png
cargo run --release -- onion "ProductScene@0..ProductScene@1.5s"  # motion trail of an entrance, writes onion.png
cargo run --release -- inspect                       # missing media/fonts, clipped text, panics in any frame
cargo run --release -- render DataScene --draft    # a part of the video, half resolution, fast preset
cargo run --release -- audio analyze --waveform w.png  # loudness (LUFS), peaks, silence per scene
cargo run --release -- render                        # the final video, writes out.mp4
cargo run --release -- preview                       # real-time GPU window with sound (space, h/l, j/k, q)
cargo test                            # frame snapshots (FFRAMES_UPDATE_SNAPSHOTS=1 to accept)
```

Times accept frames (`120`), seconds (`3.2s`), `m:ss`, percentages (`50%`), scenes (`DataScene`,
`#1`) and offsets inside scenes (`DataScene@1.5s`, `@50%`, `@end`). Add `--json` to any
command for machine-readable output.

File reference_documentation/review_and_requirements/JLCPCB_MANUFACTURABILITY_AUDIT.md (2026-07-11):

# JLCPCB Manufacturability and Component Audit

Audit date: 2026-07-11  
Design audited: `next_generation/nextgen_review/hardware/muon_telescope_v10/muon_telescope.kicad_pcb` (Rev A)

## Result

**Rev A is not orderable as a functional PCBA.** Its 107 electrical references and four mounting holes are placed, but the PCB has no routed copper segments. It also contains electrical design faults and incomplete functions documented in `NEXT_GENERATION_PCB_REVIEW.md`. Component availability alone cannot make it manufacturable.

The existing BOM has 38 purchasing lines. Most commodity lines have usable public JLCPCB/LCSC choices, but several lines are unresolved and several stocked parts must still be changed for electrical reasons. The proposed nRF9151, USB-C PD, SIM/eSIM, four Peltier drivers, extra DACs, dual thresholds, four MPPC/NTC interfaces, and revised power tree are not present in this Rev A BOM and therefore are not covered by its counts.

Stock is volatile. “In stock” below means that the official JLCPCB catalog showed public stock during this audit; it is not a reservation. Pre-order critical extended parts before releasing production.

## Existing Rev A BOM

| Qty | References | Function/value | Package | JLCPCB part | Class / stock | Decision |
|---:|---|---|---|---|---|---|
| 4 | R106,R116,R126,R136 | 2 kΩ 1% | 0402 | C4109 | Basic, in stock | Keep |
| 5 | R13,R101,R111,R121,R131 | 100 kΩ 1% | 0402 | C25741 | Basic, in stock | Keep |
| 4 | R102,R112,R122,R132 | 10 Ω 1% | 0402 | C25077 | Basic, in stock | Keep |
| 9 | R10,R103,R104,R113,R114,R123,R124,R133,R134 | 1 kΩ 1% | 0402 | C11702 | Basic, in stock | Keep |
| 4 | R105,R115,R125,R135 | 33 Ω 1% | 0402 | C25105 | Basic, in stock | Keep |
| 1 | R11 | 270 kΩ 1% | 0603 | C22965 | Basic/catalogued | Verify stock at quote |
| 3 | R12,R32,R33 | 10 kΩ 1% | 0402 | C25744 | Basic/catalogued | Keep |
| 1 | R15 | 62 kΩ 1% | 0603 | C23221 | Basic/catalogued | Keep |
| 1 | R14 | 1 MΩ 1% | 0402 | C26083 | Basic/catalogued | Keep; verify working voltage |
| 3 | R16,R30,R31 | 4.7 kΩ 1% | 0402 | C25900 | Basic/catalogued | Keep |
| 3 | R35,R36,R37 | 100 Ω 1% | 0402 | C25076 | Basic/catalogued | Remove or add actual LEDs; these currently terminate FPGA RGB pins without LEDs |
| 1 | R20 | 0 Ω link | 0402 | **none** | **Bad mapping** | Assign a real 0 Ω part; generator currently inherits 100 Ω C25076 |
| 4 | C106,C116,C126,C136 | 2.2 pF C0G | 0402 | C1559 | Basic/catalogued | Keep only after TIA re-simulation/layout parasitic budget |
| 16 | C30-C33,C102-C104,C112-C114,C122-C124,C132-C134 | 100 nF | 0402 | C1525 | Basic/catalogued | Keep; add missing FPGA/rail decoupling |
| 1 | C13 | 10 nF | 0402 | C15195 | Basic/catalogued | Keep |
| 5 | C22,C105,C115,C125,C135 | 1 µF 25 V X5R | 0402 | C52923 | Basic, in stock | Keep where DC-bias derating is acceptable |
| 2 | C20,C21 | 10 µF | 0603 | C19702 | Catalogued | Verify voltage/ripple and current stock at quote |
| 4 | C101,C111,C121,C131 | 100 nF 50 V | 0805 | TBD | Unresolved | Select exact 50 V X7R/C0G JLC part and re-check DC-bias capacitance |
| 2 | C10,C11 | 1 µF 50 V | 1206 | TBD | Unresolved | Select exact 50 V X7R JLC part |
| 1 | C12 | 2.2 µF 50 V | 1206 | TBD | Unresolved | “Film/C0G” is not credible in this footprint/value; select rated MLCC using bias curves or enlarge footprint |
| 4 | D2-D5 | BAV99,215 | SOT-23 | C2500 | Basic, in stock | Stocked, but do not use as the sole SiPM-input protection until capacitance/clamp-current review |
| 1 | D10 | SS510B | SMB | C7420368 | Extended, in stock | Keep if boost loss/layout are acceptable |
| 1 | L1 | SWPA4030S100MT, 10 µH | 4×4 mm | C38117 | Extended, in stock | Correct footprint to chosen part; 1.5 A rated, 2.4 A saturation, not “2 A” generically |
| 1 | L2 | 100 µH | 0805 | C68035 | Catalogued | Verify current, DCR, tolerance, and live stock; value alone is insufficient |
| 4 | J2-J5 | BWU.FL-IPEX1 coax | SMD | C5137195 | Extended, in stock | Stocked; **do not place SiPM HV on the exposed coax shell** in next generation |
| 3 | J1,J9,J10 | 1×2 2.54 mm vertical header | THT | TBD | Unresolved | Choose exact stocked MPN/LCSC or replace with SMT wire connector |
| 1 | J6 | 1×6 2.54 mm vertical header | THT | TBD | Unresolved | Placeholder; direct GNSS integration preferred |
| 2 | J7,J8 | 1×10 2.54 mm vertical header | THT | TBD | Unresolved | Remove; next baseline directly mounts nRF9151-LACA |
| 4 | U101,U111,U121,U131 | OPA858IDSGR | WSON-8-EP 2×2 | **C970232** | Extended, assembly-supported | Correct bogus C601618 note; circuit still electrically invalid at present 3.3 V/VBOT bias |
| 4 | U102,U112,U122,U132 | TLV3601IDBVR | SOT-23-5 | TBD | Public stock not confirmed | Pre-order/global-source or qualify a stocked comparator; verify output logic and overdrive behavior |
| 1 | U10 | TPS61170DRVR | WSON-6 2×2 | **C15163** | Extended, in stock | Correct bogus C77205 note (C77205 is an unrelated RF receiver) |
| 1 | U11 | AMS1117-3.3 | SOT-223 | C6186 | Basic, in stock | Manufacturable but poor choice for USB/Peltier system; replace with synchronous buck |
| 1 | U12 | XC6206P122MR-G | SOT-23 | C424699 | Extended, in stock | Stocked; only 60 mA rated, so verify FPGA-core peak load or replace |
| 1 | U4 | DAC7578IPWR | TSSOP-16 | TBD | Public stock not confirmed | Do not freeze; next generation needs more DAC channels and explicit reference/buffering |
| 1 | U5 | BME280 | LGA-8 | C92489 | Extended, in stock | Keep if lifecycle/cost acceptable; protect environmental opening |
| 1 | U6 | W25Q128JVSIQ | SOIC-8 208 mil | C97521 | Basic, assembly-supported | Keep; verify exact wide-SOIC courtyard and boot compatibility |
| 1 | U3 | ICE40UP5K-SG48I | QFN-48-EP 7×7 | C2678152 | Extended, in stock | Correct part is `SG48I`, not `SG48ITR`; VCCPLL must be 1.2 V, not current 3.3 V |
| 1 | X1 | 25 MHz 3.3 V oscillator/TCXO | 2520 4-pin | TBD | Unresolved | Select exact stocked part; define stability, phase noise, startup, enable polarity, and footprint |

Mounting holes H1-H4 are mechanical features and are excluded from assembly BOM quantity.

## Stocked parts required by the next-generation baseline

These are catalog feasibility findings, not yet a complete design BOM:

| Function | Candidate | JLCPCB status | Constraint |
|---|---|---|---|
| Cellular/GNSS MCU module | nRF9151-LACA-R7, C22397843 | Extended, assembly-supported | Standard PCBA only; X-ray required; stock must be rechecked/reserved |
| SiPM TIA | OPA858IDSGR, C970232 | Extended, assembly-supported | Requires a corrected analog supply/bias architecture |
| HV boost controller | TPS61170DRVR, C15163 | Extended, in stock | 38 V output limit leaves little fault margin; validate MicroFC-30035 bias range and transients |
| FPGA | ICE40UP5K-SG48I, C2678152 | Extended, in stock | Add correct 1.2 V core/PLL rail, configuration and decoupling |
| 1.2 V LDO | XC6206P122MR-G, C424699 | Extended, in stock | Marginal 60 mA ceiling; likely replace with a higher-current stocked rail part |
| Boost inductor | SWPA4030S100MT, C38117 | Extended, in stock | Footprint and current claims must match this exact MPN |

No final JLC-stocked choices have yet been selected for USB-C receptacle/ESD/PD controller, 5 V and 3.3 V converters, SIM holder/eSIM option, LTE/GNSS RF networks and antennas, four bidirectional Peltier drivers, current sensing, four NTC interfaces, MPPC connectors, extra DACs, dual comparators, programming/debug connectors, or protection. A “complete next-generation BOM” cannot honestly be issued until those circuits are designed.

## Release gates for a completely JLCPCB-manufacturable board

1. Redesign the unsafe/incomplete schematic; do not patch the Rev A BOM in isolation.
2. Give every fitted reference one exact manufacturer part number and one exact JLCPCB/LCSC number. Do not use value-only matching.
3. Use **Standard PCBA**, because nRF9151-LACA requires it and X-ray inspection.
4. Prefer one-sided SMT. Any THT connector must have a confirmed JLCPCB wave/hand-solder assembly option and exact catalog part.
5. Generate Gerbers, drill files, BOM and CPL from the same tagged KiCad commit. Confirm rotations and pin 1 for every QFN/LGA/WSON/diode/connector.
6. Pass KiCad ERC and DRC with zero unexplained violations, routed copper, filled zones, impedance/stack-up definition, and a reviewed return-current path.
7. Upload BOM/CPL to JLCPCB’s quotation tool for the intended quantity. Resolve every automatic match manually and reserve low-stock extended parts.
8. Order an electrically limited prototype run, inspect X-ray images, and perform power-rail/current-limited bring-up before connecting SiPMs or Peltiers.

## Catalog evidence

Official JLCPCB pages used include the current entries for C6186, C970232, C15163, C38117, C424699, C7420368, C5137195, C2678152, C52923, and C22397843. JLCPCB states that only matched BOM parts are populated, extended parts can incur feeder loading charges, and real-time availability must be confirmed during BOM upload. Public stock is not reserved until parts are pre-ordered into the customer library.

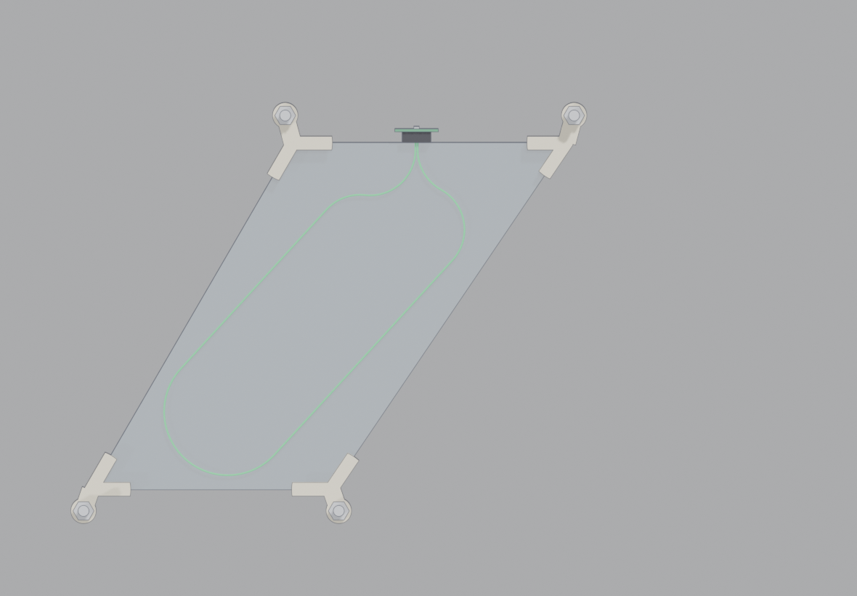
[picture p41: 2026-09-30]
hw/docs/assembly/tile08_top.png

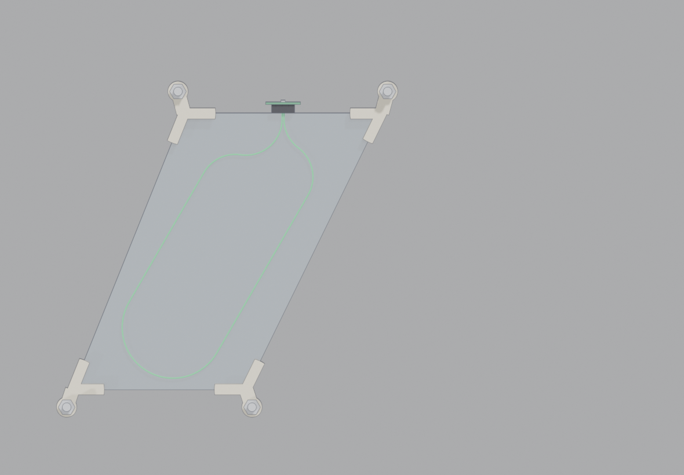
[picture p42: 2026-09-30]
hw/docs/assembly/tile06_top.png

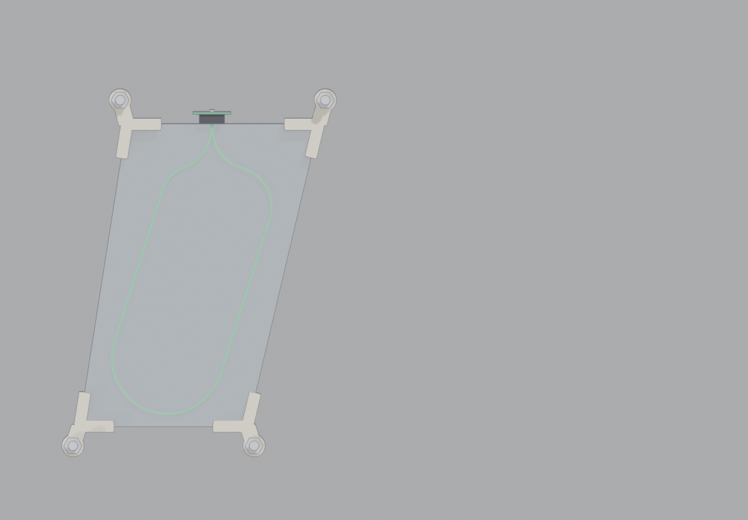
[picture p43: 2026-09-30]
hw/docs/assembly/tile03_top.png

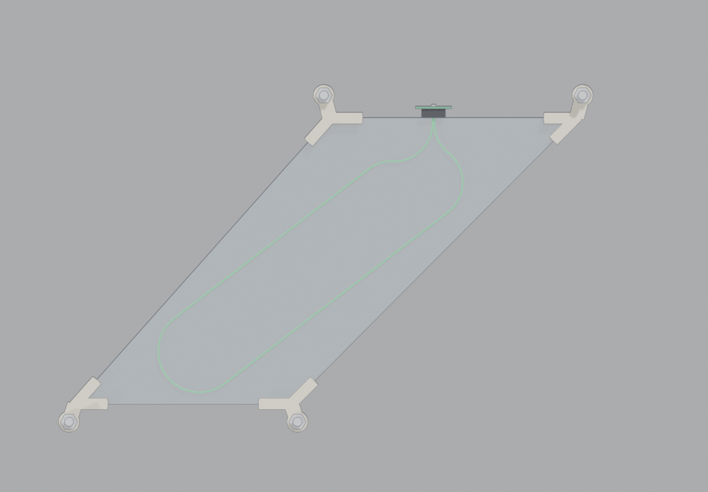
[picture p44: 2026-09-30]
hw/docs/assembly/tile11_top.png

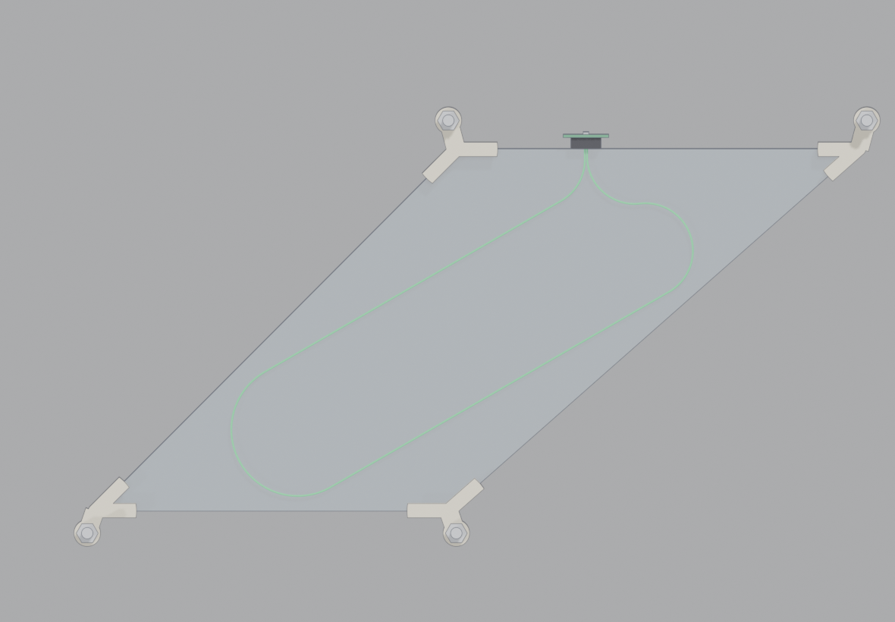
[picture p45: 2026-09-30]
hw/docs/assembly/tile12_top.png

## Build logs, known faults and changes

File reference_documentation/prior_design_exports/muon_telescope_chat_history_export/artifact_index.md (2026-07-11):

# Artifact Index

This export references these files created or uploaded during the thread.

## User-uploaded files/images

- `muonTelescope.eprj` — EasyEDA project uploaded by the user.
- Several schematic/pinout screenshots were uploaded and discussed:
  - comparator/RP pin mapping screenshot
  - BME280/DAC schematic snippets
  - ColorEasyPico2-RP2350 pinout screenshot
  - LED/button schematic screenshot

## Assistant-generated files

- `muon_telescope_project.zip` — firmware + dashboard project zip generated earlier.
- `muon_telescope_codex_hardware_handoff.md` — hardware/Codex handoff summary generated earlier.
- `visible_chat_history.md` — this transcript file.
- `artifact_index.md` — this file.

## Notes

- Sandbox links in the chat transcript are preserved as text where they appeared.
- This export includes visible conversation content only. It does not include hidden reasoning/tool scratchpad.

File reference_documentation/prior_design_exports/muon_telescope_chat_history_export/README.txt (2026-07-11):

Muon Telescope Chat History Export
==================================

This zip contains a visible chat transcript export for the 4-channel SiPM muon telescope discussion.

Files:
- visible_chat_history.md
  The reconstructed visible user/assistant conversation transcript.
- artifact_index.md
  File/artifact references from the conversation.
- muon_telescope_codex_hardware_handoff.md
  Copy of the hardware design handoff previously generated, if available.

Scope:
- Includes visible messages and described uploads/screenshots.
- Does not include hidden chain-of-thought or private tool scratchpad.

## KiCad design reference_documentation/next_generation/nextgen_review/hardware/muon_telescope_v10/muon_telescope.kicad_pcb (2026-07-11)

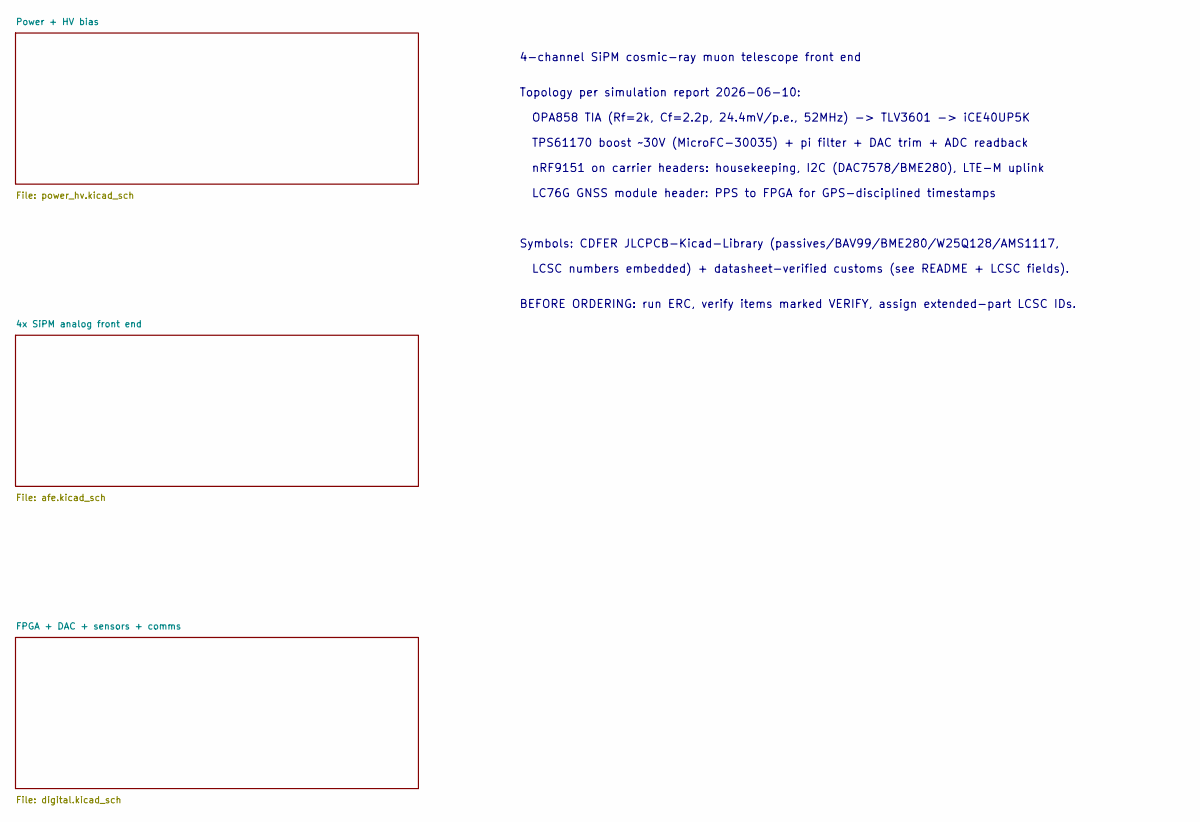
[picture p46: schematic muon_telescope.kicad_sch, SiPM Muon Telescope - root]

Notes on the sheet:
4-channel SiPM cosmic-ray muon telescope front end
Topology per simulation report 2026-06-10:
OPA858 TIA (Rf=2k, Cf=2.2p, 24.4mV/p.e., 52MHz) -> TLV3601 -> iCE40UP5K
TPS61170 boost ~30V (MicroFC-30035) + pi filter + DAC trim + ADC readback
nRF9151 on carrier headers: housekeeping, I2C (DAC7578/BME280), LTE-M uplink
LC76G GNSS module header: PPS to FPGA for GPS-disciplined timestamps
Symbols: CDFER JLCPCB-Kicad-Library (passives/BAV99/BME280/W25Q128/AMS1117,
LCSC numbers embedded) + datasheet-verified customs (see README + LCSC fields).
BEFORE ORDERING: run ERC, verify items marked VERIFY, assign extended-part LCSC IDs.

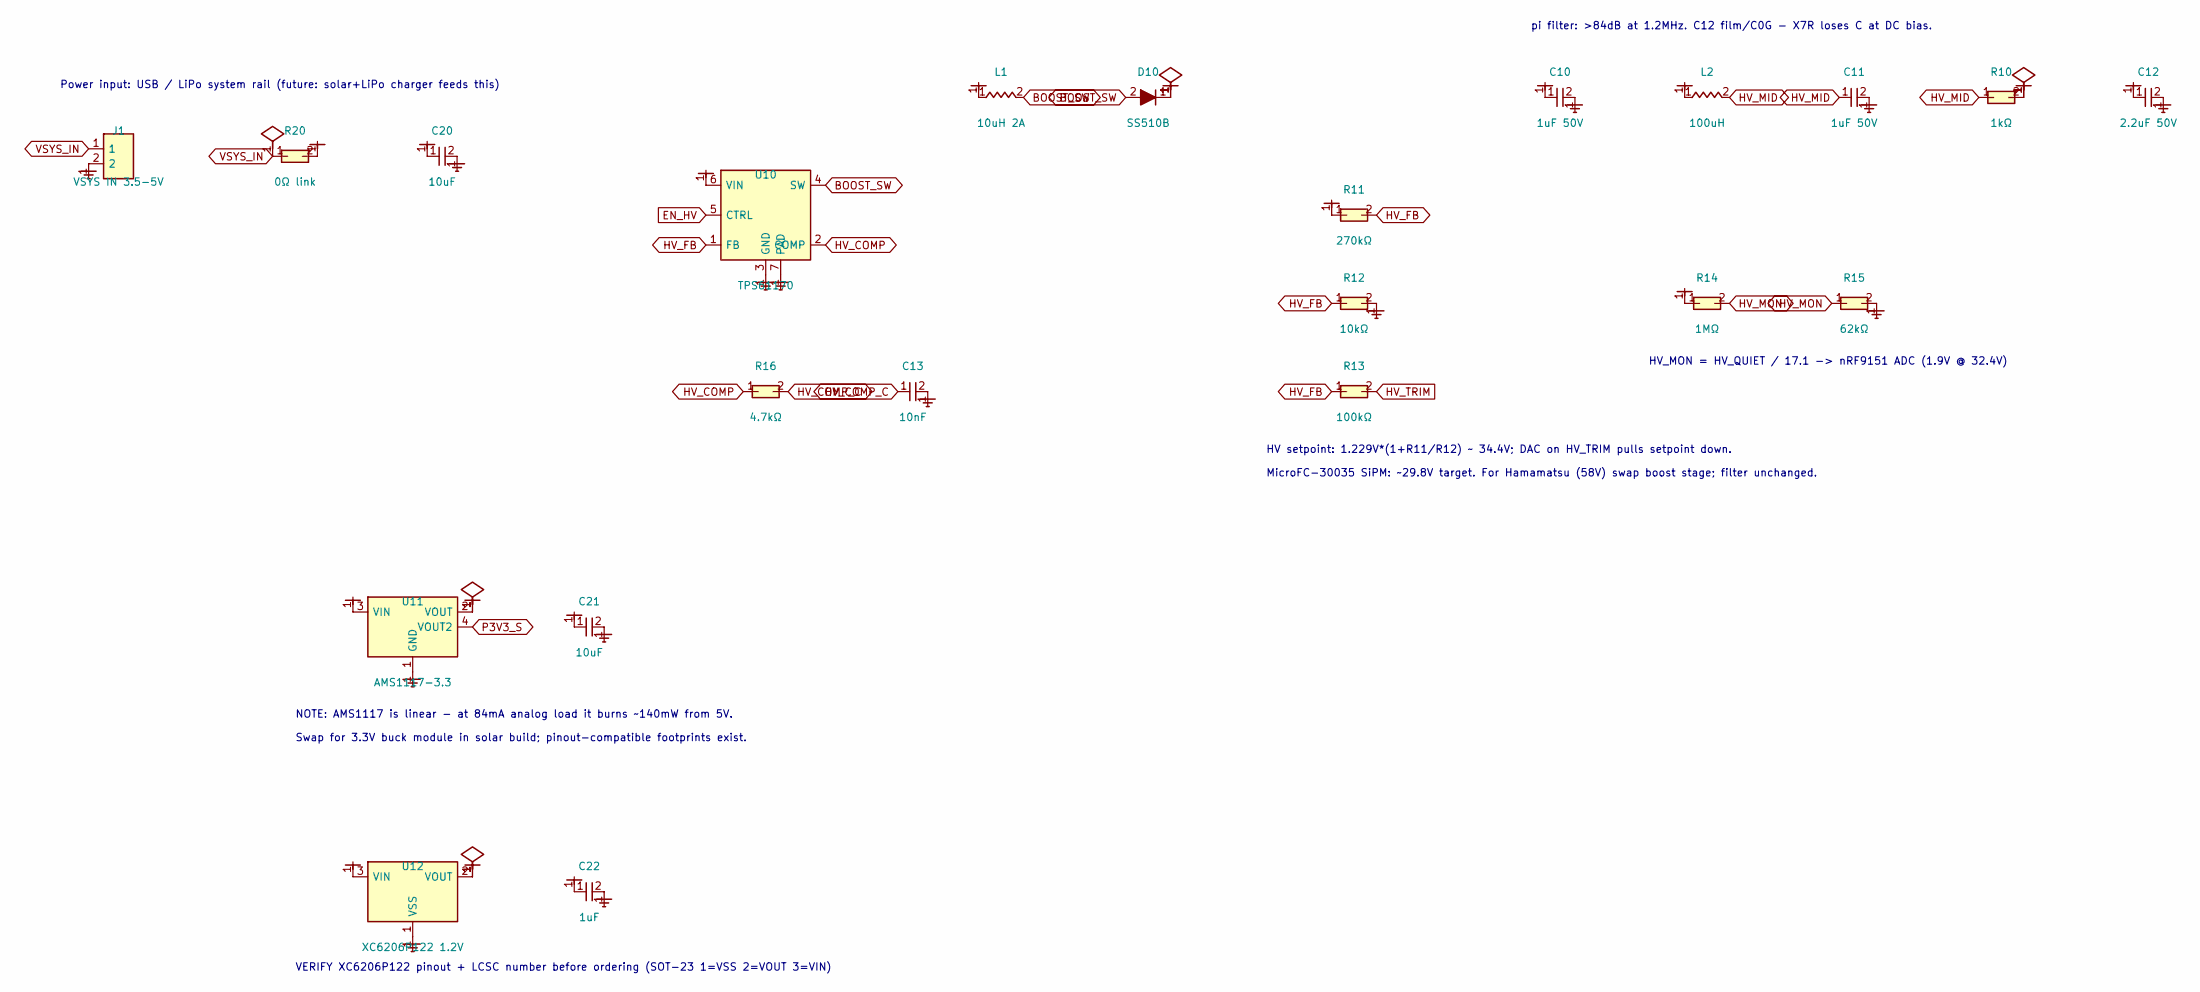
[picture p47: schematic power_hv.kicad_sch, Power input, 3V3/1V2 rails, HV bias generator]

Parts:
C10, C11: 1uF 50V; C_1206
C12: 2.2uF 50V; C_1206
C13: 10nF; C_0402; LCSC C15195
C20, C21: 10uF; C_0603; LCSC C19702
C22: 1uF; C_0402; LCSC C52923
D10: SS510B; D_SMB; LCSC C7420368
J1: VSYS IN 3.5-5V; PinHeader_1x02_P2.54mm_Vertical
L1: 10uH 2A; L_Taiyo-Yuden_NR-40xx
L2: 100uH; L_0805; LCSC C68035
R10: 1kΩ; R_0402; LCSC C11702
R11: 270kΩ; R_0603; LCSC C22965
R12: 10kΩ; R_0402; LCSC C25744
R13: 100kΩ; R_0402; LCSC C25741
R14: 1MΩ; R_0402; LCSC C26083
R15: 62kΩ; R_0603; LCSC C23221
R16: 4.7kΩ; R_0402; LCSC C25900
R20: 0Ω link; R_0402; LCSC C25076
U10: TPS61170; WSON-6-1EP_2x2mm_P0.65mm_EP1x1.6mm
U11: AMS1117-3.3; SOT-223-3_L6.5-W3.4-P2.30-LS7.0-BR; LCSC C6186
U12: XC6206P122 1.2V; SOT-23-3_L2.9-W1.6-P1.90-LS2.8-BR

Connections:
+1V2: C22.1, U12.2 (VOUT); also elsewhere on the board
+3V3: C21.1, U11.2 (VOUT), U12.3 (VIN); also elsewhere on the board
BOOST_SW: D10.2 (A), L1.2, U10.4 (SW)
EN_HV: U10.5 (CTRL); also elsewhere on the board
GND: C10.2, C11.2, C12.2, C13.2, C20.2, C21.2, C22.2, J1.2, R12.2, R15.2, U10.3 (GND), U10.7 (PAD), U11.1 (GND), U12.1 (VSS); also elsewhere on the board
HV_COMP: R16.1, U10.2 (COMP)
HV_COMP_C: C13.1, R16.2
HV_FB: R11.2, R12.1, R13.1, U10.1 (FB)
HV_MID: C11.1, L2.2, R10.1
HV_MON: R14.2, R15.1; also elsewhere on the board
HV_QUIET: C12.1, R10.2, R14.1; also elsewhere on the board
HV_RAW: C10.1, D10.1 (K), L2.1, R11.1
HV_TRIM: R13.2; also elsewhere on the board
P3V3_S: U11.4 (VOUT2)
VSYS: C20.1, L1.1, R20.2, U10.6 (VIN), U11.3 (VIN); also elsewhere on the board
VSYS_IN: J1.1, R20.1

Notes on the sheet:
Power input: USB / LiPo system rail (future: solar+LiPo charger feeds this)
HV setpoint: 1.229V*(1+R11/R12) ~ 34.4V; DAC on HV_TRIM pulls setpoint down.
MicroFC-30035 SiPM: ~29.8V target. For Hamamatsu (58V) swap boost stage; filter unchanged.
pi filter: >84dB at 1.2MHz. C12 film/C0G - X7R loses C at DC bias.
HV_MON = HV_QUIET / 17.1 -> nRF9151 ADC (1.9V @ 32.4V)
NOTE: AMS1117 is linear - at 84mA analog load it burns ~140mW from 5V.
Swap for 3.3V buck module in solar build; pinout-compatible footprints exist.
VERIFY XC6206P122 pinout + LCSC number before ordering (SOT-23 1=VSS 2=VOUT 3=VIN)

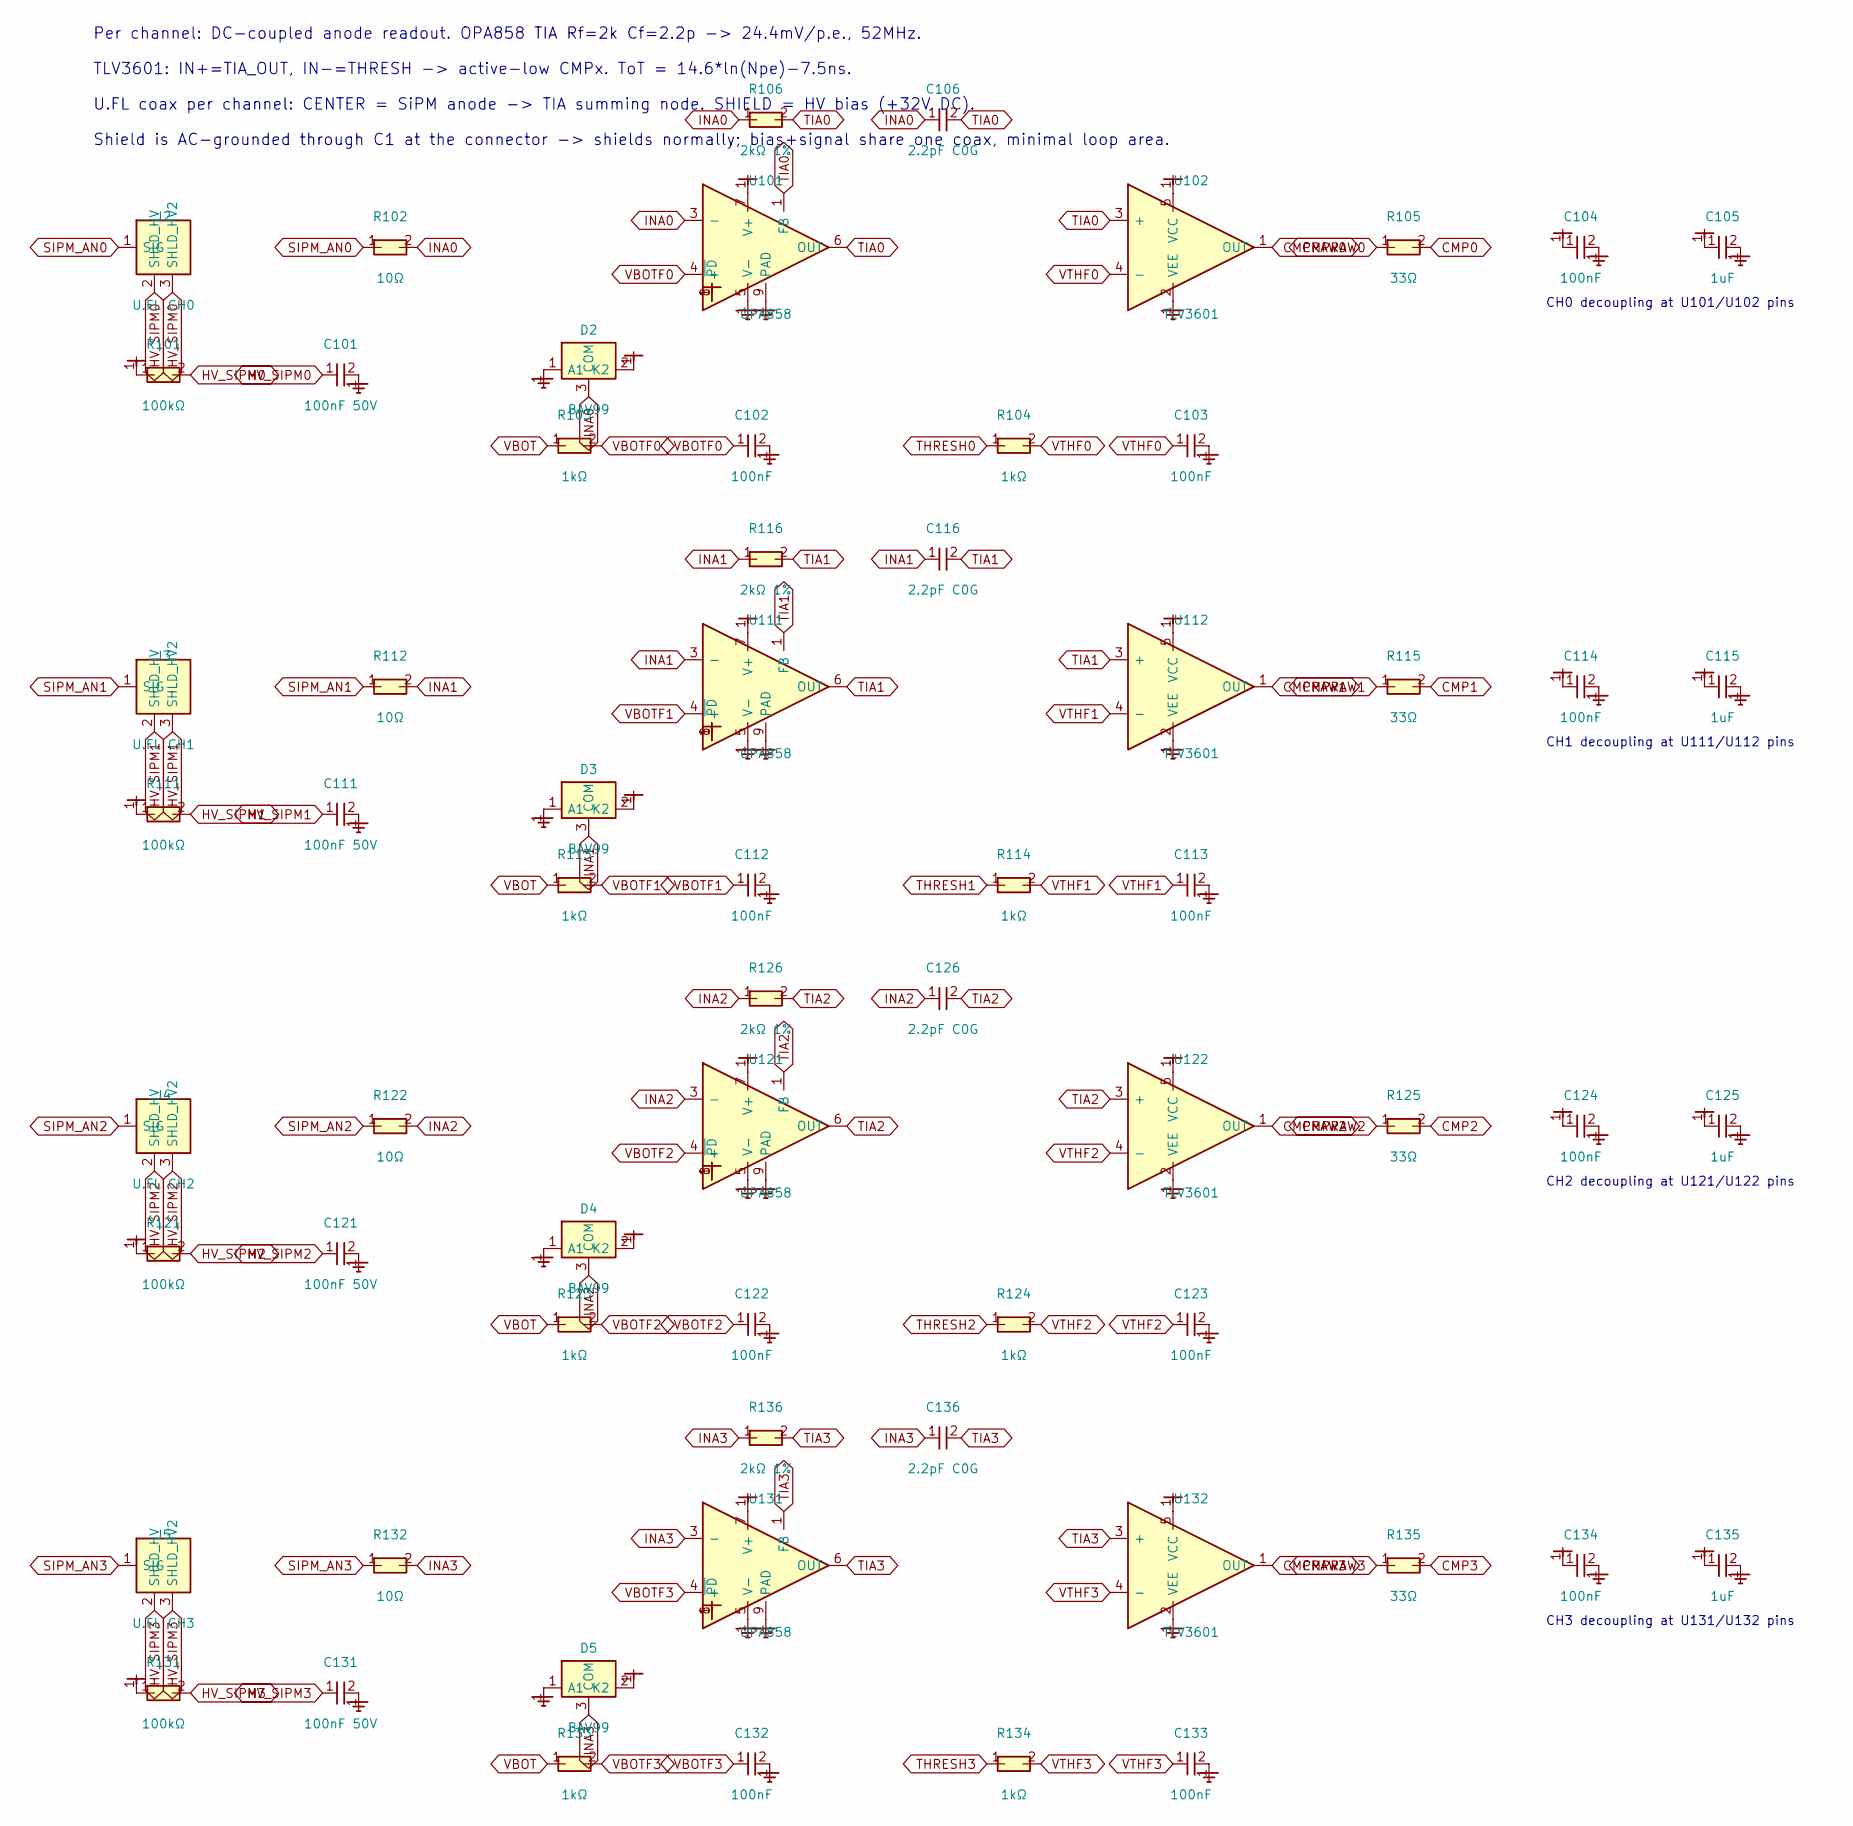
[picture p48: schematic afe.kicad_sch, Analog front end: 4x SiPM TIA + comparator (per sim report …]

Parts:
C101, C111, C121, C131: 100nF 50V; C_0805
C102, C103, C104, C112, C113, C114, C122, C123, C124, C132, C133, C134: 100nF; C_0402; LCSC C1525
C105, C115, C125, C135: 1uF; C_0402; LCSC C52923
C106, C116, C126, C136: 2.2pF C0G; C_0402; LCSC C1559
D2, D3, D4, D5: BAV99; SOT-23-3_L2.9-W1.6-P1.90-LS2.8-BR; LCSC C2500
J2: U.FL CH0; IPEX-SMD_BWIPX-1-001E; LCSC C5137195
J3: U.FL CH1; IPEX-SMD_BWIPX-1-001E; LCSC C5137195
J4: U.FL CH2; IPEX-SMD_BWIPX-1-001E; LCSC C5137195
J5: U.FL CH3; IPEX-SMD_BWIPX-1-001E; LCSC C5137195
R101, R111, R121, R131: 100kΩ; R_0402; LCSC C25741
R102, R112, R122, R132: 10Ω; R_0402; LCSC C25077
R103, R104, R113, R114, R123, R124, R133, R134: 1kΩ; R_0402; LCSC C11702
R105, R115, R125, R135: 33Ω; R_0402; LCSC C25105
R106, R116, R126, R136: 2kΩ 1%; R_0402; LCSC C4109
U101, U111, U121, U131: OPA858; WSON-8-1EP_2x2mm_P0.5mm_EP0.9x1.6mm
U102, U112, U122, U132: TLV3601; SOT-23-5

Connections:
+3V3: C104.1, C105.1, C114.1, C115.1, C124.1, C125.1, C134.1, C135.1, D2.2 (K2), D3.2 (K2), D4.2 (K2), D5.2 (K2), U101.7 (V+), U101.8 (~PD), U102.5 (VCC), U111.7 (V+), U111.8 (~PD), U112.5 (VCC), U121.7 (V+), U121.8 (~PD), U122.5 (VCC), U131.7 (V+), U131.8 (~PD), U132.5 (VCC); also elsewhere on the board
CMP0: R105.2; also elsewhere on the board
CMP1: R115.2; also elsewhere on the board
CMP2: R125.2; also elsewhere on the board
CMP3: R135.2; also elsewhere on the board
CMPRAW0: R105.1, U102.1 (OUT)
CMPRAW1: R115.1, U112.1 (OUT)
CMPRAW2: R125.1, U122.1 (OUT)
CMPRAW3: R135.1, U132.1 (OUT)
GND: C101.2, C102.2, C103.2, C104.2, C105.2, C111.2, C112.2, C113.2, C114.2, C115.2, C121.2, C122.2, C123.2, C124.2, C125.2, C131.2, C132.2, C133.2, C134.2, C135.2, D2.1 (A1), D3.1 (A1), D4.1 (A1), D5.1 (A1), U101.5 (V-), U101.9 (PAD), U102.2 (VEE), U111.5 (V-), U111.9 (PAD), U112.2 (VEE), U121.5 (V-), U121.9 (PAD), U122.2 (VEE), U131.5 (V-), U131.9 (PAD), U132.2 (VEE); also elsewhere on the board
HV_QUIET: R101.1, R111.1, R121.1, R131.1; also elsewhere on the board
HV_SIPM0: C101.1, J2.2 (SHLD_HV), J2.3 (SHLD_HV2), R101.2
HV_SIPM1: C111.1, J3.2 (SHLD_HV), J3.3 (SHLD_HV2), R111.2
HV_SIPM2: C121.1, J4.2 (SHLD_HV), J4.3 (SHLD_HV2), R121.2
HV_SIPM3: C131.1, J5.2 (SHLD_HV), J5.3 (SHLD_HV2), R131.2
INA0: C106.1, D2.3 (COM), R102.2, R106.1, U101.3 (-)
INA1: C116.1, D3.3 (COM), R112.2, R116.1, U111.3 (-)
INA2: C126.1, D4.3 (COM), R122.2, R126.1, U121.3 (-)
INA3: C136.1, D5.3 (COM), R132.2, R136.1, U131.3 (-)
SIPM_AN0: J2.1 (SIG), R102.1
SIPM_AN1: J3.1 (SIG), R112.1
SIPM_AN2: J4.1 (SIG), R122.1
SIPM_AN3: J5.1 (SIG), R132.1
THRESH0: R104.1; also elsewhere on the board
THRESH1: R114.1; also elsewhere on the board
THRESH2: R124.1; also elsewhere on the board
THRESH3: R134.1; also elsewhere on the board
TIA0: C106.2, R106.2, U101.1 (FB), U101.6 (OUT), U102.3 (+)
TIA1: C116.2, R116.2, U111.1 (FB), U111.6 (OUT), U112.3 (+)
TIA2: C126.2, R126.2, U121.1 (FB), U121.6 (OUT), U122.3 (+)
TIA3: C136.2, R136.2, U131.1 (FB), U131.6 (OUT), U132.3 (+)
VBOT: R103.1, R113.1, R123.1, R133.1; also elsewhere on the board
VBOTF0: C102.1, R103.2, U101.4 (+)
VBOTF1: C112.1, R113.2, U111.4 (+)
VBOTF2: C122.1, R123.2, U121.4 (+)
VBOTF3: C132.1, R133.2, U131.4 (+)
VTHF0: C103.1, R104.2, U102.4 (-)
VTHF1: C113.1, R114.2, U112.4 (-)
VTHF2: C123.1, R124.2, U122.4 (-)
VTHF3: C133.1, R134.2, U132.4 (-)

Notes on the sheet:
Per channel: DC-coupled anode readout. OPA858 TIA Rf=2k Cf=2.2p -> 24.4mV/p.e., 52MHz.
TLV3601: IN+=TIA_OUT, IN-=THRESH -> active-low CMPx. ToT = 14.6*ln(Npe)-7.5ns.
U.FL coax per channel: CENTER = SiPM anode -> TIA summing node. SHIELD = HV bias (+32V DC).
Shield is AC-grounded through C1 at the connector -> shields normally; bias+signal share one coax, minimal loop area.
CH0 decoupling at U101/U102 pins
CH1 decoupling at U111/U112 pins
CH2 decoupling at U121/U122 pins
CH3 decoupling at U131/U132 pins

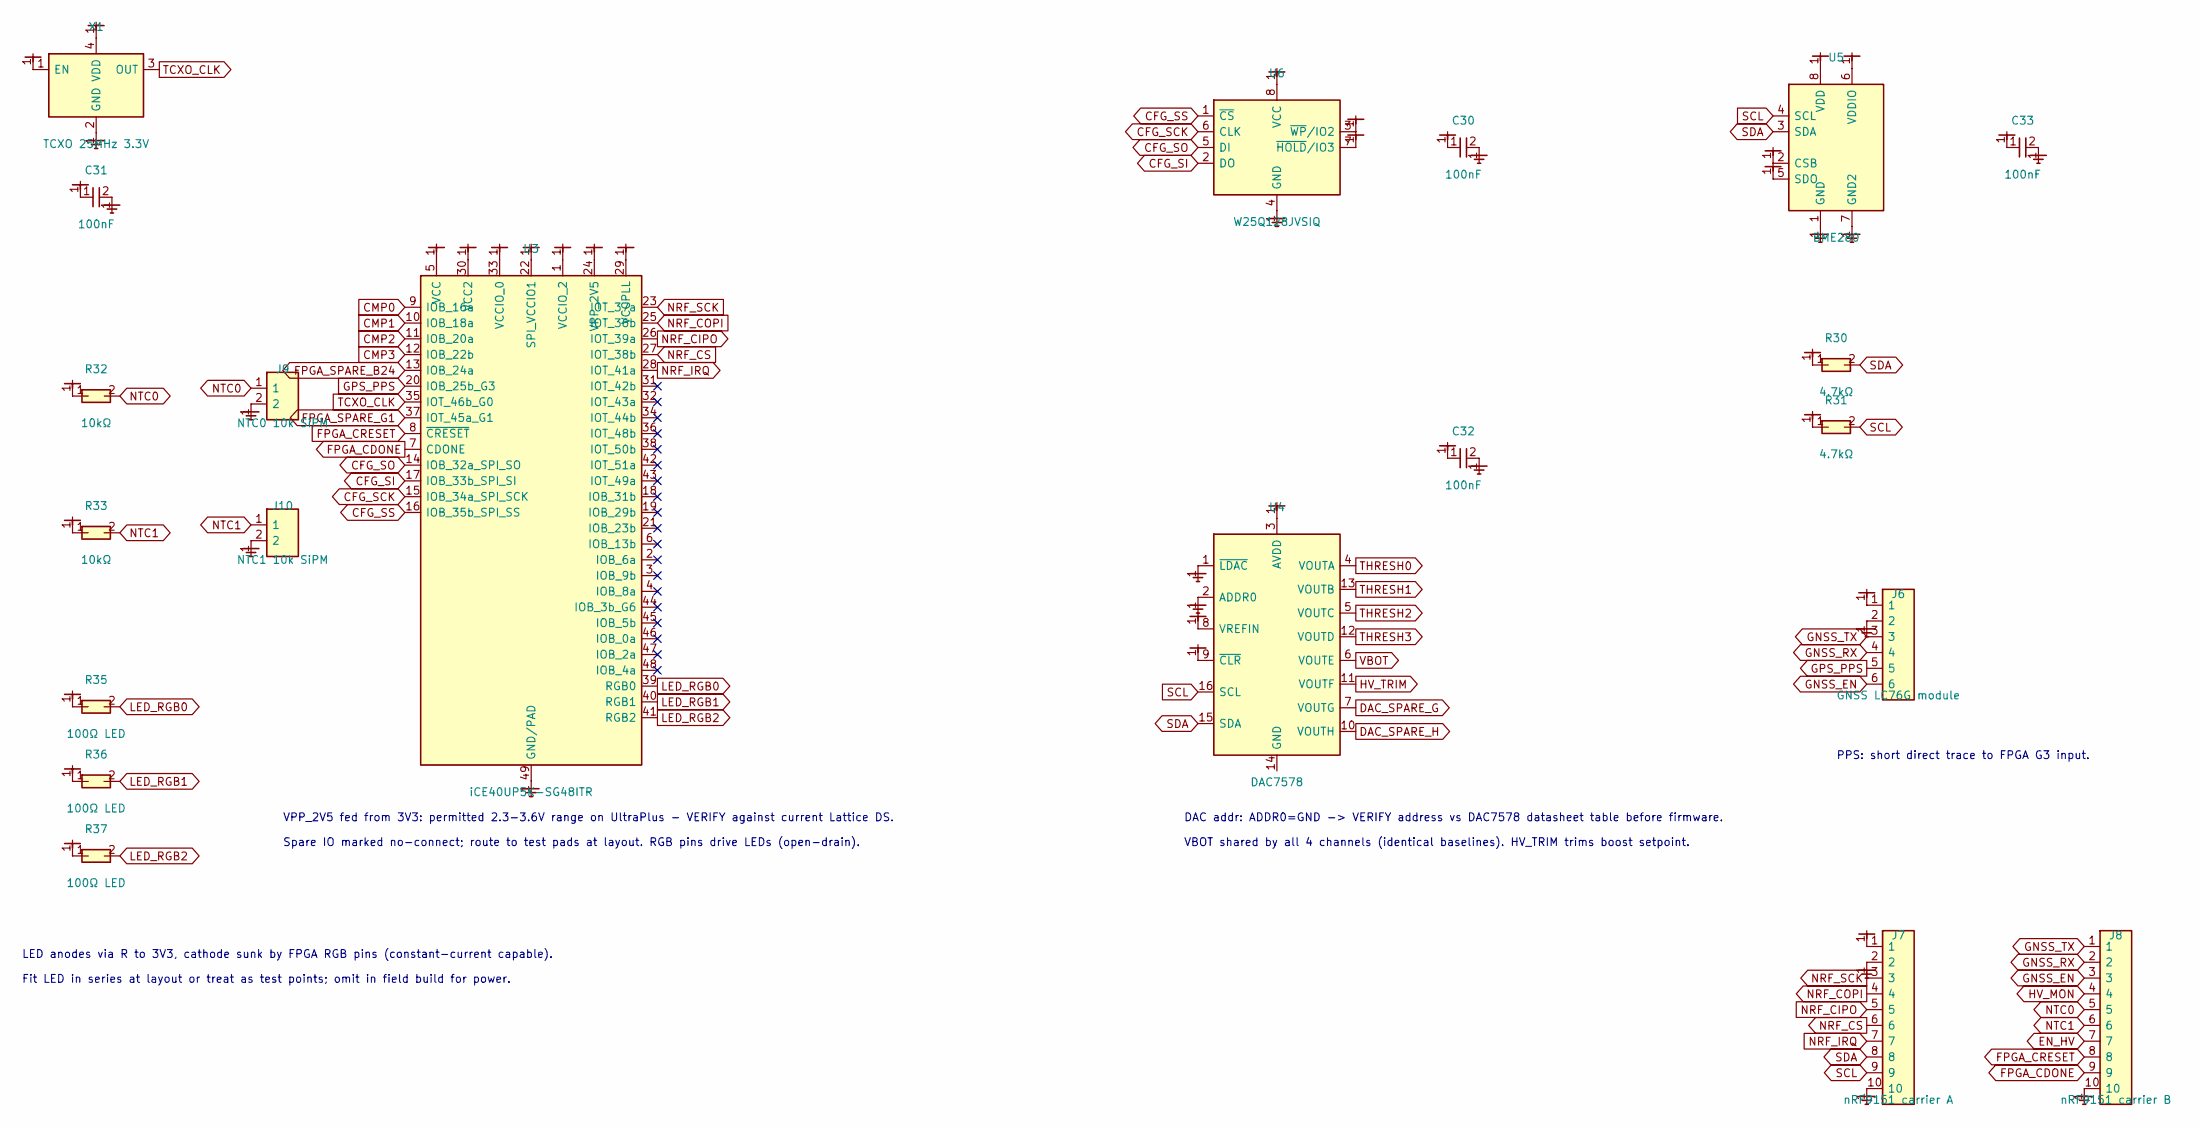
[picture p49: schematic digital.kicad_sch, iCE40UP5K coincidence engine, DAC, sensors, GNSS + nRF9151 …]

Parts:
C30, C31, C32, C33: 100nF; C_0402; LCSC C1525
J6: GNSS LC76G module; PinHeader_1x06_P2.54mm_Vertical
J7: nRF9151 carrier A; PinHeader_1x10_P2.54mm_Vertical
J8: nRF9151 carrier B; PinHeader_1x10_P2.54mm_Vertical
J9: NTC0 10k SiPM; PinHeader_1x02_P2.54mm_Vertical
J10: NTC1 10k SiPM; PinHeader_1x02_P2.54mm_Vertical
R30, R31: 4.7kΩ; R_0402; LCSC C25900
R32, R33: 10kΩ; R_0402; LCSC C25744
R35, R36, R37: 100Ω LED; R_0402; LCSC C25076
U3: iCE40UP5K-SG48ITR; QFN-48-1EP_7x7mm_P0.5mm_EP5.6x5.6mm
U4: DAC7578; TSSOP-16_4.4x5mm_P0.65mm
U5: BME280; Bosch_LGA-8_2.5x2.5mm_P0.65mm_ClockwisePinNumbering; LCSC C92489
U6: W25Q128JVSIQ; SOIC-8_L5.3-W5.3-P1.27-LS8.0-BL; LCSC C97521
X1: TCXO 25MHz 3.3V; Oscillator_SMD_ECS_2520MV-xxx-xx-4Pin_2.5x2.0mm

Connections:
+1V2: U3.5 (VCC), U3.30 (VCC2); also elsewhere on the board
+3V3: C30.1, C31.1, C32.1, C33.1, J6.1, R30.1, R31.1, R32.1, R33.1, R35.1, R36.1, R37.1, U3.1 (VCCIO_2), U3.22 (SPI_VCCIO1), U3.24 (VPP_2V5), U3.29 (VCCPLL), U3.33 (VCCIO_0), U4.3 (AVDD), U4.8 (VREFIN), U4.9 (~CLR), U5.2 (CSB), U5.5 (SDO), U5.6 (VDDIO), U5.8 (VDD), U6.3 (~WP/IO2), U6.7 (~HOLD/IO3), U6.8 (VCC), X1.1 (EN), X1.4 (VDD); also elsewhere on the board
CFG_SCK: U3.15 (IOB_34a_SPI_SCK), U6.6 (CLK)
CFG_SI: U3.17 (IOB_33b_SPI_SI), U6.2 (DO)
CFG_SO: U3.14 (IOB_32a_SPI_SO), U6.5 (DI)
CFG_SS: U3.16 (IOB_35b_SPI_SS), U6.1 (~CS)
CMP0: U3.9 (IOB_16a); also elsewhere on the board
CMP1: U3.10 (IOB_18a); also elsewhere on the board
CMP2: U3.11 (IOB_20a); also elsewhere on the board
CMP3: U3.12 (IOB_22b); also elsewhere on the board
DAC_SPARE_G: U4.7 (VOUTG)
DAC_SPARE_H: U4.10 (VOUTH)
EN_HV: J8.7; also elsewhere on the board
FPGA_CDONE: J8.9, U3.7 (CDONE)
FPGA_CRESET: J8.8, U3.8 (~CRESET)
FPGA_SPARE_B24: U3.13 (IOB_24a)
FPGA_SPARE_G1: U3.37 (IOT_45a_G1)
GND: C30.2, C31.2, C32.2, C33.2, J6.2, J7.2, J7.10, J8.10, J9.2, J10.2, U3.49 (GND/PAD), U4.1 (~LDAC), U4.2 (ADDR0), U5.1 (GND), U5.7 (GND2), U6.4 (GND), X1.2 (GND); also elsewhere on the board
GNSS_EN: J6.6, J8.3
GNSS_RX: J6.4, J8.2
GNSS_TX: J6.3, J8.1
GPS_PPS: J6.5, U3.20 (IOB_25b_G3)
HV_MON: J8.4; also elsewhere on the board
HV_TRIM: U4.11 (VOUTF); also elsewhere on the board
LED_RGB0: R35.2, U3.39 (RGB0)
LED_RGB1: R36.2, U3.40 (RGB1)
LED_RGB2: R37.2, U3.41 (RGB2)
NRF_CIPO: J7.5, U3.26 (IOT_39a)
NRF_COPI: J7.4, U3.25 (IOT_36b)
NRF_CS: J7.6, U3.27 (IOT_38b)
NRF_IRQ: J7.7, U3.28 (IOT_41a)
NRF_SCK: J7.3, U3.23 (IOT_37a)
NTC0: J8.5, J9.1, R32.2
NTC1: J8.6, J10.1, R33.2
SCL: J7.9, R31.2, U4.16 (SCL), U5.4 (SCL)
SDA: J7.8, R30.2, U4.15 (SDA), U5.3 (SDA)
TCXO_CLK: U3.35 (IOT_46b_G0), X1.3 (OUT)
THRESH0: U4.4 (VOUTA); also elsewhere on the board
THRESH1: U4.13 (VOUTB); also elsewhere on the board
THRESH2: U4.5 (VOUTC); also elsewhere on the board
THRESH3: U4.12 (VOUTD); also elsewhere on the board
VBOT: U4.6 (VOUTE); also elsewhere on the board
VSYS: J7.1; also elsewhere on the board

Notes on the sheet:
VPP_2V5 fed from 3V3: permitted 2.3-3.6V range on UltraPlus - VERIFY against current Lattice DS.
Spare IO marked no-connect; route to test pads at layout. RGB pins drive LEDs (open-drain).
DAC addr: ADDR0=GND -> VERIFY address vs DAC7578 datasheet table before firmware.
VBOT shared by all 4 channels (identical baselines). HV_TRIM trims boost setpoint.
PPS: short direct trace to FPGA G3 input.
LED anodes via R to 3V3, cathode sunk by FPGA RGB pins (constant-current capable).
Fit LED in series at layout or treat as test points; omit in field build for power.

Board: 4 copper layers, 111 parts (0 on the bottom side), 75 nets, no tracks yet.

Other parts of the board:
H1, H2, H3, H4: M3; MountingHole_3.2mm_M3

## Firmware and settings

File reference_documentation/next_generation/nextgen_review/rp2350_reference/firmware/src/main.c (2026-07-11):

#include <stdio.h>
#include <string.h>
#include <stdint.h>
#include <stdbool.h>

#include "pico/stdlib.h"
#include "pico/multicore.h"
#include "hardware/pio.h"
#include "hardware/i2c.h"
#include "hardware/irq.h"
#include "hardware/timer.h"

#include "tusb.h"

#include "edge_fall.pio.h"
#include "proto.h"
#include "bme280.h"
#include "dac7578.h"

// --- Pin map (from your schematic) ---
#define PIN_CH0 16
#define PIN_CH1 17
#define PIN_CH2 18
#define PIN_CH3 19
#define PIN_MAX1932_INT 22

#define PIN_I2C_SDA 4
#define PIN_I2C_SCL 5

// I2C addresses
#define BME280_ADDR 0x77  // SDO tied high
#define DAC7578_ADDR 0x4C // common default (see Adafruit docs)

// --- Capture ring buffer (core1 -> core0) ---
typedef struct { uint8_t ch; uint32_t ts; } edge_evt_t;
#define EVT_Q_SIZE 2048
static edge_evt_t evt_q[EVT_Q_SIZE];
static volatile uint32_t evt_w = 0;
static volatile uint32_t evt_r = 0;
static volatile uint32_t evt_drop = 0;

static inline bool evt_push(uint8_t ch, uint32_t ts) {
  uint32_t w = evt_w;
  uint32_t n = (w + 1) & (EVT_Q_SIZE - 1);
  if (n == evt_r) { evt_drop++; return false; }
  evt_q[w] = (edge_evt_t){ .ch = ch, .ts = ts };
  __compiler_memory_barrier();
  evt_w = n;
  return true;
}

static inline bool evt_pop(edge_evt_t* out) {
  uint32_t r = evt_r;
  if (r == evt_w) return false;
  *out = evt_q[r];
  __compiler_memory_barrier();
  evt_r = (r + 1) & (EVT_Q_SIZE - 1);
  return true;
}

// --- Counters ---
static uint32_t singles[4];
static uint32_t subset_counts[16]; // exact subset counts by mask index (1..15)

// exact subset masks ordering for report
static const uint8_t subset_order[11] = { 3,5,9,6,10,12,7,11,13,14,15 };

// --- Coincidence clustering state ---
static bool cluster_active = false;
static uint32_t cluster_tmin = 0;
static uint32_t cluster_tmax = 0;
static uint8_t cluster_mask = 0;
static uint32_t holdoff_until = 0;

// Config
static uint32_t report_period_ms = 60000;
static uint16_t window_ticks = 20;   // in PIO-loop ticks (not ns); adjust from dashboard
static uint16_t holdoff_ticks = 20;

// Status
static uint32_t err_flags = 0;
static uint32_t period_index = 0;
static absolute_time_t boot_time;

// I2C
static i2c_inst_t* I2C = i2c0;
static bool bme_ok = false;
static bool dac_ok = false;
static uint16_t dac_code[8] = {0,0,0,0, 0,0,0,0}; // 12-bit codes

// --- Helpers ---
static inline uint32_t uptime_ms(void) {
  return to_ms_since_boot(get_absolute_time());
}

static inline uint32_t ticks_diff(uint32_t a, uint32_t b) {
  return (uint32_t)(a - b); // wrap-safe unsigned
}

static void close_cluster_if_active(void) {
  if (!cluster_active) return;
  if (cluster_mask >= 1 && cluster_mask <= 15) {
    if (cluster_mask != 0) subset_counts[cluster_mask]++;
  }
  holdoff_until = cluster_tmax + holdoff_ticks;
  cluster_active = false;
  cluster_mask = 0;
}

static void on_leading_edge(uint8_t ch, uint32_t ts) {
  // raw singles always count
  if (ch < 4) singles[ch]++;

  // MAX1932 fault pin latch
  if (gpio_get(PIN_MAX1932_INT) == 0) err_flags |= ERR_MAX1932_INT;

  // coincidence processing
  if (ticks_diff(ts, holdoff_until) < 0x80000000u) { // ts >= holdoff_until in unsigned sense?
    // This check is tricky with wrap; simplest: if (ts - holdoff_until) has MSB set, ts < holdoff_until.
    // We'll do that:
  }
  // better wrap-safe:
  if ((int32_t)(ts - holdoff_until) < 0) {
    return;
  }

  uint8_t bit = (uint8_t)(1u << ch);
  if (!cluster_active) {
    cluster_active = true;
    cluster_tmin = cluster_tmax = ts;
    cluster_mask = bit;
    return;
  }

  // If within window from cluster start, merge; else close and start new
  if ((uint16_t)(ts - cluster_tmin) <= window_ticks) {
    cluster_tmax = ts;
    cluster_mask |= bit;
  } else {
    close_cluster_if_active();
    cluster_active = true;
    cluster_tmin = cluster_tmax = ts;
    cluster_mask = bit;
  }
}

static void reset_counters(void) {
  memset(singles, 0, sizeof(singles));
  memset(subset_counts, 0, sizeof(subset_counts));
  cluster_active = false;
  cluster_mask = 0;
  holdoff_until = 0;
  evt_drop = 0;
}

// --- USB framing payload packing ---
static uint16_t pack_u16(uint8_t* p, uint16_t v){ p[0]=v&0xFF; p[1]=v>>8; return 2; }
static uint16_t pack_u32(uint8_t* p, uint32_t v){ p[0]=v&0xFF; p[1]=v>>8; p[2]=v>>16; p[3]=v>>24; return 4; }
static uint16_t pack_i16(uint8_t* p, int16_t v){ return pack_u16(p, (uint16_t)v); }

static void send_report(bme280_reading_t bme) {
  uint8_t payload[256];
  uint16_t off = 0;

  off += pack_u32(payload+off, period_index);
  off += pack_u32(payload+off, report_period_ms);
  off += pack_u16(payload+off, window_ticks);
  off += pack_u16(payload+off, holdoff_ticks);

  for (int i=0;i<4;i++) off += pack_u32(payload+off, singles[i]);

  for (int i=0;i<11;i++) {
    uint8_t m = subset_order[i];
    off += pack_u32(payload+off, subset_counts[m]);
  }

  off += pack_i16(payload+off, bme.temp_c_x100);
  off += pack_u16(payload+off, bme.hum_rh_x100);
  off += pack_u32(payload+off, bme.press_pa);

  for (int i=0;i<8;i++) off += pack_u16(payload+off, dac_code[i]);

  off += pack_u32(payload+off, evt_drop);
  off += pack_u32(payload+off, err_flags);
  off += pack_u32(payload+off, uptime_ms());

  if (!proto_send_report(payload, off)) {
    err_flags |= ERR_USB_BACKLOG;
  }
}

// --- Command handling ---
static void handle_cmd(uint8_t cmd_id, uint8_t seq, const uint8_t* args, uint16_t arg_len) {
  uint8_t status = 0;
  uint8_t ret[64];
  uint16_t ret_len = 0;

  switch (cmd_id) {
    case CMD_SET_REPORT_PERIOD_MS:
      if (arg_len != 4) { status = 1; break; }
      report_period_ms = (uint32_t)args[0] | ((uint32_t)args[1]<<8) | ((uint32_t)args[2]<<16) | ((uint32_t)args[3]<<24);
      if (report_period_ms < 200) report_period_ms = 200;
      break;

    case CMD_SET_WINDOW_TICKS:
      if (arg_len != 2) { status = 1; break; }
      window_ticks = (uint16_t)args[0] | ((uint16_t)args[1]<<8);
      break;

    case CMD_SET_HOLDOFF_TICKS:
      if (arg_len != 2) { status = 1; break; }
      holdoff_ticks = (uint16_t)args[0] | ((uint16_t)args[1]<<8);
      break;

    case CMD_RESET_COUNTERS:
      if (arg_len != 0) { status = 1; break; }
      reset_counters();
      period_index = 0;
      break;

    case CMD_DAC_SET_CH: {
      if (arg_len != 3) { status = 1; break; }
      uint8_t ch = args[0];
      uint16_t code = (uint16_t)args[1] | ((uint16_t)args[2]<<8);
      if (ch > 7 || code > 4095) { status = 2; break; }
      dac_code[ch] = code;
      if (!dac7578_write_channel(I2C, DAC7578_ADDR, ch, code)) {
        err_flags |= ERR_DAC_FAIL; status = 3;
      }
      break;
    }

    case CMD_DAC_SET_ALL: {
      if (arg_len != 16) { status = 1; break; }
      for (int i=0;i<8;i++) {
        uint16_t code = (uint16_t)args[i*2] | ((uint16_t)args[i*2+1]<<8);
        dac_code[i] = (code & 0x0FFF);
      }
      if (!dac7578_write_all(I2C, DAC7578_ADDR, dac_code)) {
        err_flags |= ERR_DAC_FAIL; status = 3;
      }
      break;
    }

    case CMD_DAC_GET_ALL: {
      if (arg_len != 0) { status = 1; break; }
      // return cached values (device is source of truth)
      for (int i=0;i<8;i++) {
        ret[ret_len++] = (uint8_t)(dac_code[i] & 0xFF);
        ret[ret_len++] = (uint8_t)(dac_code[i] >> 8);
      }
      break;
    }

    case CMD_GET_STATUS: {
      // Return: period_ms(u32), window(u16), holdoff(u16), err_flags(u32), uptime_ms(u32)
      ret_len = 0;
      ret_len += pack_u32(ret+ret_len, report_period_ms);
      ret_len += pack_u16(ret+ret_len, window_ticks);
      ret_len += pack_u16(ret+ret_len, holdoff_ticks);
      ret_len += pack_u32(ret+ret_len, err_flags);
      ret_len += pack_u32(ret+ret_len, uptime_ms());
      break;
    }

    default:
      status = 0xFF;
      break;
  }

  if (!proto_send_ack(cmd_id, seq, status, ret, ret_len)) {
    err_flags |= ERR_USB_BACKLOG;
  }
}

// --- Core1: PIO capture ---
static void core1_entry(void) {
  PIO pio = pio0;
  uint offset = pio_add_program(pio, &edge_fall_program);

  // Configure GPIOs as inputs with pull-ups (active-low pulses)
  const uint pins[4] = {PIN_CH0, PIN_CH1, PIN_CH2, PIN_CH3};
  for (int i=0;i<4;i++) {
    gpio_init(pins[i]);
    gpio_set_dir(pins[i], GPIO_IN);
    gpio_pull_up(pins[i]);
  }

  uint sm_mask = 0;
  for (int ch=0; ch<4; ch++) {
    uint sm = ch; // SM 0..3
    pio_sm_config c = edge_fall_program_get_default_config(offset);

    // Use JMP PIN for this channel
    sm_config_set_jmp_pin(&c, pins[ch]);

    // RX FIFO only, joined for deeper FIFO
    sm_config_set_fifo_join(&c, PIO_FIFO_JOIN_RX);

    // Run at full pio clock (clkdiv=1)
    sm_config_set_clkdiv(&c, 1.0f);

    pio_sm_init(pio, sm, offset, &c);
    pio_sm_set_enabled(pio, sm, false);
    sm_mask |= (1u << sm);
  }

  // Start all SMs in sync
  pio_enable_sm_mask_in_sync(pio, sm_mask);

  while (true) {
    // Drain FIFO for each SM
    for (int ch=0; ch<4; ch++) {
      uint sm = ch;
      while (!pio_sm_is_rx_fifo_empty(pio, sm)) {
        uint32_t ts = pio_sm_get(pio, sm);
        evt_push((uint8_t)ch, ts);
      }
    }
    tight_loop_contents();
  }
}

int main() {
  stdio_init_all();
  boot_time = get_absolute_time();

  // MAX1932 INT input (active low)
  gpio_init(PIN_MAX1932_INT);
  gpio_set_dir(PIN_MAX1932_INT, GPIO_IN);
  gpio_pull_up(PIN_MAX1932_INT);

  // I2C init
  i2c_init(I2C, 400 * 1000);
  gpio_set_function(PIN_I2C_SDA, GPIO_FUNC_I2C);
  gpio_set_function(PIN_I2C_SCL, GPIO_FUNC_I2C);
  gpio_pull_up(PIN_I2C_SDA);
  gpio_pull_up(PIN_I2C_SCL);

  bme_ok = bme280_init(I2C, BME280_ADDR);
  if (!bme_ok) err_flags |= ERR_BME_FAIL;

  dac_ok = dac7578_init(I2C, DAC7578_ADDR);
  if (!dac_ok) err_flags |= ERR_DAC_FAIL;

  // Apply initial DAC codes
  if (!dac7578_write_all(I2C, DAC7578_ADDR, dac_code)) err_flags |= ERR_DAC_FAIL;

  // USB init
  tusb_init();

  // Launch capture core
  multicore_launch_core1(core1_entry);

  absolute_time_t next_report = make_timeout_time_ms(report_period_ms);

  while (true) {
    tud_task();

    // RX bytes -> parser
    if (tud_cdc_available()) {
      uint8_t buf[64];
      uint32_t n = tud_cdc_read(buf, sizeof(buf));
      for (uint32_t i=0;i<n;i++) {
        bool ok = proto_try_parse_byte(buf[i]);
        (void)ok;
      }
    }

    // Handle parsed commands
    if (proto_have_cmd()) {
      uint8_t cmd_id, seq;
      uint16_t arg_len;
      uint8_t args[512];
      if (proto_pop_cmd(&cmd_id, &seq, &arg_len, args, sizeof(args))) {
        handle_cmd(cmd_id, seq, args, arg_len);
      } else {
        err_flags |= ERR_RX_FRAMING;
      }
    }

    // Process captured edges
    edge_evt_t ev;
    while (evt_pop(&ev)) {
      on_leading_edge(ev.ch, ev.ts);
    }

    // Report timer
    if (absolute_time_diff_us(get_absolute_time(), next_report) <= 0) {
      // Flush cluster so last event doesn't get lost at boundary
      close_cluster_if_active();

      bme280_reading_t bme = bme280_read(I2C, BME280_ADDR);
      if (!bme.ok) {
        err_flags |= ERR_BME_FAIL;
        // keep last values as zero
      }

      send_report(bme);

      // Increment period
      period_index++;

      // Reset counters for next period
      reset_counters();

      // Schedule next report with drift-free increment
      next_report = delayed_by_ms(next_report, report_period_ms);
    }

    tight_loop_contents();
  }
}

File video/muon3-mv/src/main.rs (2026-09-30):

use muon3_mv::{MusicVideo, HEIGHT, WIDTH};
use fframes::{EncoderOptions, MediaDirectory, RenderOptions, cli};
use fframes_skia_renderer::{SkiaFFramesRenderer, SkiaPipelineConcurrencyPolicy, SkiaPipelineConfig, metal::SkiaMetalCtx};
use std::process::ExitCode;

/// Standard fframes commands: render, frame, strip, onion, inspect, timeline, audio, preview (`--help`).
#[derive(Debug, clap::Args)]
struct VideoArgs {}

use fframes::cli::clap;

fn main() -> ExitCode {
    let args = cli::parse::<VideoArgs>();
    // runtime media directory: fonts, images and the song are read at run time
    let dir = MediaDirectory::read_folder(concat!(env!("CARGO_MANIFEST_DIR"), "/media")).expect("media folder");
    let media = dir.process_media_source().expect("media");
    let video = MusicVideo::new();
    let gpu = SkiaMetalCtx::new(WIDTH, HEIGHT).expect("GPU context");

    cli::new(
        &video,
        RenderOptions {
            media: Some(&media),
            video_encoder_options: EncoderOptions {
                preferred_encoder: Some("libx264"),
                codec_params: Some(&[("crf", "18"), ("preset", "medium"), ("tune", "animation")]),
                ..Default::default()
            },
            ..Default::default()
        },
    )
    .args(args)
    .backend(
        SkiaFFramesRenderer::new_metal(
            &gpu,
            SkiaPipelineConfig { concurrency_policy: SkiaPipelineConcurrencyPolicy::MaxPerformance, ..Default::default() },
        )
        .expect("skia renderer"),
    )
    .preview(fframes_native_player::cli_preview)
    .run()
}

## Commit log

2026-07-11 Initialize muon telescope engineering archive
    Create an umbrella repository for the complete muonTelescope project lineage while preserving all 28 upstream repositories as submodules with their original histories and remotes.
    Archive the legacy hardware, firmware, gateware, CAD, detector mechanics, data-service, and documentation projects alongside the 2026 KiCad design package, simulations, generated schematics, placement artifacts, RP2350 reference implementation, and prior decision/chat exports.
    Add public GSU and sPHENIX research references plus a publication index connecting the 20x20x1 cm loop-fiber panel geometry, historical detector performance, and atmospheric correction requireme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
    [afe.kicad_sch, digital.kicad_sch, muon_telescope.kicad_pcb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]
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2026-07-11 Record schematic-freeze decisions and select CP30238 TEC
    All ten pre-freeze questions were answered on 2026-07-11; capture them as
    binding architecture decisions and close the TEC research item.
    Decisions recorded:
    - 100% JLCPCB assembly including the TEC section: DRV8873HPWPR frozen
    (ITRIP <= 2.5 A, output LC filter); MAX1968 and daughterboard dropped.
    - USB-C PD input only this revision (CH224K); battery/solar storage stays
    in an external qualified module, no BQ25798-class charger on board.
    - TEC module selected: Same Sky CP30238, 20 x 20 x 3.8 mm, 8.6 V / 3 A,
    Qmax 15 W, dTmax 66 degC, ~2.3 ohm, Digi-Key 102-1667-ND. Operating
    point 1.2-1.8 A for a 15-25 degC drop; per-channel st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
    [bom.csv, selection_matrix.csv]
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2026-07-11 Improve simulation infrastructure, add Geant4 stand-in, ROOT charts and LaTeX reports
    - Update .gitignore to exclude generated artifacts (.venv, results/, plots/, PDFs, CSVs, etc.)
    - Refine ngspice circuit scripts for reliable parametric runs (temp netlist substitution, fixed control blocks)
    - Add Python Geant4 stand-in (geant4_panel_standin.py) that produces hits.csv, yield maps, spectra and timing profiles for reports when full Geant4 build is not yet available
    - Add comprehensive reporting layer under sim/reports/:
    - muon3_simulation_report.tex (full LaTeX source with sections for AFE, detector, system models, tables and figures)
    - build_reports.py (generates self-contained PDF using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
2026-07-11 Stable state: Add comprehensive Muon3 simulation studies paper (LaTeX, sPHENIX-style formatting with citations); implement Geant4 model improvements (realistic cosmic spectrum+angles, better loop geo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
    This captures a solid checkpoint for simulations + documentation before full Geant4 completion and sim binary rerun.
    [muon3.kicad_pcb]
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2026-07-11 feat: compare sim results to literature, improvements/fixes, combined plots in paper, full build
    - Compared Geant4 results ( ~79 p.e. mean / ~28 p.e./MeV for 1cm EJ-200 looped WLS+SiPM ) against publications:
    * CUPID muon veto (arXiv:2505.06129): 52.9-57.2 p.e./MeV for similar 1cm panels
    * Other WLS+SiPM muon strips: 10-30 p.e./side typical
    * Our yield a bit lower than CUPID best (due to loop geometry, single-end, simplified groove)
    - Improvements & fixes:
    * Increased reflector reflectivity 0.92 -> 0.96
    * WLS eff 0.85 -> 0.90
    * Fixed photon production counting in PanelSteppingAction (now properly estimates from edep * 10000 ph/MeV)
    * Updated WLS creator process detection
    * Re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
2026-07-11 Update everything: layman summaries, Google Photos/Drive connectors for docs/sims/data/tests, multi-account support, rclone integration, enhanced pull scripts, PCB design refinements, Muon3Vision ass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
    - Added/updated layman summaries in main READMEs (physics, pcb, Muon3Vision, sim)
    - Full Google Photos connector with date/keyword filtering to explore library for data and tests
    - New Google Drive pull script for simulations and additional information
    - Support for all accounts via separate OAuth / rclone remotes
    - Installed rclone; documented connectors after system check (no desktop sync active)
    - Updated scripts/, .gitignore, build_paper.sh --pull-images, ma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
    [BME280_LGA8.step, DFN_WSON_approx.step, ESOP8.step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]
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2026-07-11 Update paper with latest architecture, add openEMS EM simulations (RF, SI, PDN), update schematics with real symbols/wires, add 3D models and openEMS figures
    [afe.kicad_sch, cable_50cm_sparams.csv, connectors_sensors.kicad_sch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]
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2026-07-11 Run real openEMS FDTD simulations (now that Python bindings installed); update paper and figures with authentic results for antenna, cable, traces, PDN. Rebuild PDF.
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2026-07-11 Activate real openEMS Python bindings for EM sims; refresh results and paper
    - Verified openEMS + CSXCAD import and basic FDTD objects work with Homebrew python 3.14.
    - Updated all sim/openems/scripts/*.py to properly detect HAS_OPENEMS=True, label plots/titles/prints as 'openEMS FDTD' (vs synthetic fallback).
    - Re-ran the four simulations (antenna, cable SI, HS trace, PDN); updated plots in sim/openems/plots/ and copied to figures/openems/.
    - Updated sim/openems/README.md with current success status and run instructions.
    - Revised Muon3_Simulation_Studies.tex openEMS section + captions for accuracy (FDTD framework active; representative results from the suite).
    - Rebuilt paper PDF.
    This de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
2026-07-11 Expand thermal / Peltier analysis and integrate into main paper
    - Enhanced sim/python/thermal_peltier.py with:
    - Heat-leak sensitivity sweep (R_leak impact on achievable dT).
    - Worst-case ambient (35 C / 80 % RH) highlighting interlock necessity.
    - Rough 4-channel system trade-off (dT vs. DCR reduction vs. yield vs. power).
    - New plot: thermal_leak_sweep.png.
    - Copied all key thermal plots (step, sweep, PI loop, leak sensitivity) to figures/.
    - Added new dedicated \subsection{Thermal Management (Peltier / TEC)} in Muon3_Simulation_Studies.tex with two multi-minipage figures, model equations, quantitative requirements summary, and power budget tie-in.
    - Rebuilt paper (now 11 pages wit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
2026-07-11 Update READMEs for current project state
    - physics/README.md: expanded Simulations section (openEMS FDTD, enhanced thermal, Blender procedural renders); updated Paper description (11 pages, dedicated Thermal subsection with figures, Hardware Baseline Blender renders).
    - sim/README.md: bumped date to 2026-07-12; detailed thermal_peltier.py enhancements (leak sweep, PI loop, trade-offs, plots now in figures/ + paper); clarified openEMS real bindings + labeling.
    - sim/openems/README.md: bumped date; noted paper integration and current page count.
    - .gitignore: added sim/plots/ (generated outputs like other sim/*/plots/).
    - Cleanup: removed untracked sim/plots/ dir and root LaTeX temps (*.aux et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
2026-07-11 Add figures and renders to READMEs
    - physics/README.md: Added 'Selected Figures & Renders' section with Blender panel renders (isometric/top/side/front) and thermal plots.
    - cad/blender/README.md: Embedded the 4 procedural panel renders.
    - sim/openems/README.md: Added example results with all openEMS plots (antenna, cable, trace, PDN).
    - sim/README.md: Embedded thermal figures (step/sweep/PI/loop/leak) and power budget chart with relative paths.
    These match the visualizations now in the paper (Hardware Baseline, Thermal Management subsection, openEMS section). Committed and pushed.
2026-07-15 Add sPHENIX Inner HCal tiles, STEP assemblies, and Geant4 optical runs.
    Vendors phyxch/sPHENIX_HCal tile originals, builds FreeCAD STEP assemblies
    with fibers/coatings/light blockers/SiPMs, wires the hcal_tile Geant4 app,
    and updates README/paper figures with Blender renders and simulation plots.
    [InnerHCalTile01_EJ200_assembly.step, InnerHCalTile02_EJ200_assembly.step, InnerHCalTile03_EJ200_assembly.step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]
2026-07-15 Freeze HCal-tile path on Hamamatsu S12572 with LT3482 bias.
    Primary detector is S12572-33-015P on decommissioned sPHENIX tiles; station HV
    is LT3482 (JLCPCB C515895) at ~70 V. Update BOM/parts, Geant4 SiPM model, and
    ngspice AFE/HV decks; keep MicroFC+TPS61170 as legacy reference only.
    [bom.csv, hcal_tile_hits.csv, selection_matrix.csv]
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2026-07-20 Add tscircuit placement/autorouter bridge into KiCad
    Wire Muon3 tscircuit placement and the capacity autorouter into the KiCad
    workflow: export circuit-json to a reference KiCad project, stamp zone
    fences/keepouts into muon3.kicad_pcb, run a netted autoroute demo, and
    document the full bridge (coords, scripts, limits for RF/AFE/HV).
    [muon3.kicad_pcb, muon3_autoroute_demo.kicad_pcb, muon3_autoroute_demo.kicad_sch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]
2026-07-22 board: scaffold repo-root tscircuit board-as-code + fabrication pipeline
    Elevate tscircuit to the repository root as the electrical source of truth
    for the Muon3 four-channel controller, replacing the placement-only bridge
    in pcb/tscircuit/. Full board-as-code building to JLCPCB fabrication outputs.
    - package.json/tsconfig/tscircuit.config: bun toolchain, TS pinned to 5.x
    (TS 7 / tsgo breaks tsci's rollup-typescript plugin).
    - .gitignore: negate the blanket *.json rule for the project manifests;
    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
    [bom.csv, muon3-board.kicad_pcb, pnp.csv]
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2026-07-22 board: author AFE channel 0 as real board-as-code (OPA858 + dual TLV3601)
    First subsystem authored end-to-end with vendored exact JLC parts and a
    verified netlist, per the "one subsystem fully correct" plan.
    board/afe.tsx — one AFE channel wired from sim/circuit/afe_hamamatsu_s12572.cir:
    - OPA858 TIA: IN_NEG = summing node (INA), IN_POS = VBOT ref, Rf 15k ‖ Cf
    1.5p on the FB pin (FB is internally tied to OUT per the TI datasheet —
    lower-parasitic feedback), OUT drives the comparators, PD tied high.
    - 1N4148W (C2128) rail clamps on INA to VANA/GND (unambiguous vs a 3-pin
    BAV99, which imported as a generic diode).
    - dual TLV3601 (C2974371): signal on IN_POS, DAC threshold (RC-filt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
    [bom.csv, muon3-board.kicad_pcb, pnp.csv]
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2026-07-22 board: make `bun run dev` stable (scope dev to board/, move imports inside)
    The tscircuit dev server crashed ~5 s after start (both in CI and locally):
    its file-watch reset handler (POST /api/events/reset, 5 s timeout, 3 retries)
    enumerates every file under the project dir, and from the repo root that
    walks the huge reference_documentation/, submodules, sim data, and PDFs —
    so the reset times out and the process aborts. Not a parts-engine issue
    (disabling it didn't help) and we're already on the newest tsci.
    Fix: keep the project dir small.
    - `dev` script now `cd board && tsci dev index.tsx` → tscircuit watches only
    board/ (ready in ~150 ms, verified stable 8/8 over 32 s).
    - Move impo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
2026-07-22 board: actually commit the dev-scope fix (prior commit staged stale copy)
    8292efd's message described the fix but a concurrent rewrite of package.json
    (editor format-on-save / linter) reverted it before `git add`, so HEAD kept
    `dev: tsci dev board/index.tsx` (repo-root scope → the file-walk crash).
    This commits the working-tree fix from the index:
    - dev: `cd board && tsci dev index.tsx`
    - tsconfig types: + "tscircuit"
2026-07-22 board: 4-layer floorplan + AFE x4 placement (power/size/trace-width aware)
    Design the placement for the 160x120 4-layer board from the frozen
    requirements (pcb/SCHEMATIC_FREEZE_CHECK.md, DESIGN_RULES.md).
    - board/layout.ts: single-source floorplan — 4-layer stackup, six zones
    (RF | AFE x4 | HV over DIGITAL / POWER / TEC), AFE channel anchors,
    antenna keepout, M3 holes, and a net-class trace-width table (12V TEC
    1.5mm pour, per-TEC/TEC-out 0.8mm @2.5A, 5V_A star 0.4mm, HV 0.25mm
    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
    [bom.csv, muon3-board.kicad_pcb, pnp.csv]
2026-07-22 board: datasheet-driven AFE/HV placement (RF/noise/high-speed)
    Optimize the placed front-end from vendor layout guidance.
    OPA858 TIA (TI SLOS879):
    - 10 Ω series R moved directly to the IN− pin (damp bond-wire/stray-C
    resonance) instead of up by the connector.
    - VS decoupling (C_TIA) tight to VS_POS; Rf/Cf kept on the FB pin (min
    feedback parasitics) and close to FB/IN−.
    - No-pour <keepout> under IN−/OUT/FB on top + L2 reference plane to strip
    summing-node parasitic capacitance (one per channel).
    - Off-board SiPM (50 cm cable, fixed) → minimize the on-board connector→
    TIA path; cable modeled in cable_50cm.cir.
    TLV3601: VCC decoupling tightened to the pin.
    LT3482 HV (ADI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
    [bom.csv, muon3-board.kicad_pcb, pnp.csv]
2026-07-22 board: complete decoupling + rail reservoirs for placed ICs
    Add the required passives for the currently-placed subsystems (AFE x4,
    HV); per-IC passives for the not-yet-placed digital/TEC/power ICs go in
    with those ICs (their pins define the nets).
    - OPA858: add per-channel 2.2uF local bulk (C_TIAB) alongside the 0.1uF
    at VS+ (TI SLOS879 layout: 0.1uF + 2.2uF).
    - board/rails.tsx: distributed bulk reservoirs on the rails the placed
    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
    [bom.csv, muon3-board.kicad_pcb, pnp.csv]
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2026-07-22 board: populate POWER + RF, board now fully placed (230 components)
    - power.tsx: USB-C receptacle (bottom edge, clear of corner hole) -> CH224K
    PD sink (CC pull-downs, CFG code stub for 12V, VDD decoupling, PG pull-up)
    -> TPS62933 3.3V buck with full network (in/out caps, 4.7uH inductor,
    BST/SS/RT, FB divider for 3.3V, EN pull-up).
    - rf.tsx: nRF9151-LACA placed with VDD/VIO/VDD_GPIO, DEC0 cap, reset/enable
    pull-ups, supply decoupling; ANT -> U.FL edge-launch (single shared
    LTE+GNSS, 50 ohm, no matching, per Nordic). Import aliased (lowercase
    export name reads as an intrinsic JSX element otherwise).
    Whole board: RF | AFE x4 | HV over DIGITAL / POWER / TEC — 230 placements,
    49 B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
    [bom.csv, muon3-board.kicad_pcb, pnp.csv]
2026-07-23 board: swap DAC to non-BGA DAC80508MRTER (WQFN-16) and wire it
    Checked JLCPCB: the BGA DAC80508ZYZFR (grid-only balls, unwireable) has a
    non-BGA sibling. DAC80508MRTER — 16-bit, 8-ch, SPI, WQFN-16-EP(3x3),
    C2679529, SMT/Standard PCBA — matches the freeze spec with functional pins.
    Live stock is low (11 in stock, order qty 10, ~$20); the 14-bit
    DAC70508MRTER (C2679508) has only 7 — reserve stock early or qualify at
    order time.
    - Replace the placed BGA with two DAC80508MRTER (16 outputs per freeze),
    fully wired: VDD on 5 V analog, VIO on 3.3 V SPI logic, GND/EP to GND,
    internal 2.5 V reference (REF 1uF cap), CS/SCLK/SDI on the SPI bus, and
    OUT0-7 broken out to per-DAC nets; VDD/VI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
    [bom.csv, muon3-board.kicad_pcb, pnp.csv]
2026-07-23 board: ratsnest topology analysis + placement optimization (-24% weighted)
    Add tools/ratsnest.py: builds the ratsnest (per-net MST), weights nets by a
    datasheet/DESIGN_RULES routing priority (RF 10 > AFE hi-Z 8 > ... > power 1
    > GND 0), and reports weighted airwire length + zone crossings.
    Verdict: macro-topology is sound — ZERO w>=4 nets cross a zone (RF/AFE/HV/
    high-speed digital all stay local; only power/GND span the board).
    Optimizations (weighted airwire 6642 -> 5078, -24%):
    - AFE bias/thresholds made per-channel (VBOTF, V*_DAC) instead of board-
    spanning shared nets: kills the 98/69 mm nets AND fixes the freeze
    requirement for independent per-channel thresholds.
    - Dropped the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
    [muon3-board.kicad_pcb, pnp.csv]
2026-07-23 board: debug bay + test points + inter-IC bus connectivity (265 comp, DRC-clean)
    Debuggability / connectivity pass.
    Debug bay (board/debug.tsx) in the free pocket between DIGITAL and HV:
    - 14 labelled test points: all rails (VANA/VDIG/V12/VCORE/V1V2/GND) +
    SPI/I2C buses + GNSS PPS + the *divided* HV monitor (never raw 70 V).
    - per-channel TP_AO analog probe on each AFE TIA output (in afe.tsx,
    next to the channel to avoid a long summing-node stub).
    - SWD headers (RP2040 + nRF9151), iCE40 SPI-config header (J_CFG),
    stdio-UART header; vertical/doubleRow so they column cleanly.
    - RUN + BOOTSEL buttons; power-good + heartbeat status LEDs.
    Connectivity closed (were single-pad stubs):
    - RP2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
    [bom.csv, muon3-board.kicad_pcb, pnp.csv]
2026-07-23 board: rename debug.tsx → debugbay.tsx (fixes tsci dev eval crash)
    The browser evaluator behind `tsci dev` (@tscircuit/eval) resolves a relative
    import of `./debug` against the ubiquitous `debug` npm package, so
    `import { Debug } from "./debug"` came back undefined and the whole board
    failed to render in the live preview with "Element type is invalid … got
    undefined". `tsci build` (real bun path resolution) was unaffected, which is
    why the fab build passed the whole time.
    Reproduced with a CircuitRunner harness over the fsMap: a named import from
    `./debug` fails while the identical file at `./other` (or a default import)
    works. Renamed the module to `debugbay.tsx`; the board now evaluat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
2026-09-29 docs: 2026-09-29 max-scope architecture freeze (ESP32-S3, head boards, 18650, RAK3172 LoRa)
    Add pcb/MUON3_MAX_SCOPE_ARCHITECTURE.md and pcb/key_parts_max_scope.csv. Record decisions #1-#12 (frozen 2026-09-29) in pcb/freeze_questions.md, superseding the Jul 11 nRF9151-primary / RP2040 / nRF54 / CH224K / hybrid-connector / Nordic-antenna items. Note the resolved power contradiction in SCHEMATIC_FREEZE_CHECK.md, point README at the new spec (Rev A and tscircuit board predate it; do not order), add an ADR entry, and add GSU COSMIC web captures. Open: SIM provider, TEC sites, signing-key/CA/MQTT ownership.
    [key_parts_max_scope.csv]
2026-09-29 hw: Muon3 station Rev B as TypeScript board-as-code; remove legacy trees
    New hw/ package: netlist (design.ts), floorplan + force-directed placement,
    grid router with rip-up/PathFinder history and GND plane fan-out, taut +
    arc-filleted copper, Gerber X2 writer with native arcs, Excellon with slots,
    JS DRC, kicad-cli DRC oracle export, JLC BOM/CPL and a landed-cost model.
    Board: 100x150 mm, 6 layers, 4x edge SMA (HV on shell) for sPHENIX inner-HCal
    tiles (S12572), OPA356 TIA + LMV7219 per channel, MAX1932 bias (2v2 topology),
    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
    [BME280_LGA8.step, DFN_WSON_approx.step, ESOP8.step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]
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2026-09-29 hw: MC34063 bias (PWM trim, boot-safe), SMA bottom tabs unpasted (one-sided assembly)
    Replaces MAX1932 ($6.09 -> $0.15 at 100). Behavioural ngspice sim
    (hw/sim/hv_mc34063.cir): regulates at 69.0 V, 3 mV pp at the SiPM.
    84x50 mm, 4 layers, 117 placements. kicad-cli DRC: 0 / 0.
    100-board GSU run ~$19.9/board ex-works (estimate).
2026-09-29 hw: Rev C station — U.FL inside the case, identical channel cells, re-simulated bias/thermal/EMI
    Board (96 x 64 mm, 4-layer, one-sided JLC):
    - Tile inputs on Hirose U.FL-R-SMT-1(80) inside the case; bias never on an outside surface.
    - Four identical channel cells: ch0 placed + routed once, copied at 20 mm pitch (place.ts, autoroute.ts
    routeCells, twin-aware smoothing in copper.ts); 18/18 local-net copies + GND fan-out identical, verified.
    - Bias: MCP4728 trim + HV_EN gate (52.9-83.0 V, ~4 V until enabled), RC post-filter, 136 mA peak.
    - BME280 on a slotted island with no plane/vias, >= 20 mm from any input; 5 V routed at 0.5 mm.
    - Silk: per-cell labels, probe row, U.FL/HV notes; collisio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
2026-09-30 Rev C.1: external-antenna ESP32, tile-stack assembly for all 12 shapes, fixed Geant4 light transport, repo cleanup
    Board
    - ESP32-S3-WROOM-1U-N16R8 (U.FL, antenna on the lid): no antenna keep-out; pin table copied from the -1 module (EasyEDA's symbol is truncated).
    - Placement: parts of <= 6 pads may rotate in 15-degree steps; copper: pad-matched tapered exits (119 steps). KiCad DRC 0, cells identical.
    - Case: pigtail hole + FPC antenna recess in the lid, floor mounting holes; M3 socket-head screws into heat-set inserts throughout.
    Assembly (hw/case/assembly.py, render_assembly.py, build_assemblies.sh, assembly_doc.py)
    - Hierarchical FreeCAD document per tile shape: tiles 100 mm apart, groov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
    [cable_50cm_sparams.csv, hcal_tile_hits.csv, hs_trace_sparams.csv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]
2026-09-30 Rev D: long board behind the stack, closed fiber loops, coating/wrap, single README
    - Board: 337x40 mm strip, channel cell k behind tile k (100 mm pitch), identical 57 mm coax;
    display and STEMMA QT removed; 155 parts, KiCad DRC 0 errors, cells identical (tools/cell_identity.py)
    - Case: three printed segments on three plate bars; assembly.py adds coating + wrap layers,
    per-tile STEP export; renders incl. bare panels and layer explosion
    - Fibers: one closed loop per tile shape (cad/sphenix_hcal/scripts/fiber_loop.py), shared by
    FreeCAD and Geant4; retract the wrong "source CAD fiber" claims
    - Geant4: closed loop, hull-following coating/wrap shells, crossing-muon statistics
    (36.6 p.e.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
    [InnerHCalTile01_EJ200_assembly.step, InnerHCalTile01_assembly.step, InnerHCalTile02_EJ200_assembly.step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]
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2026-09-30 Music video: Nordic hyperpop story from Geant4 to the live app (fframes, ElevenLabs Music)
    One muon through every simulation: Geant4 tile light, ngspice pulse chain, SiPM bias, board heat, Wi-Fi interference,
    tile stacking, ending on the gLowCost Now screen. Generated SVG per frame, cuts on the 168 BPM bar grid.
    [lib.rs, main.rs, scenes.rs]
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
